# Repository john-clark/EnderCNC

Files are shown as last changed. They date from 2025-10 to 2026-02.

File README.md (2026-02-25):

<div align="center">








## Ender3CNC

Ender3CNC view 1

### About This Project
Got too many Enders laying around? Don't need a [5th Trident?](https://github.com/yell3D/Ender3dent) Well! Try the Ender3CNC, born from a lack of sleep, a wish to learn more CAD and too many spare parts floating around.

</div>

### Reused from the Ender 3
* Frame
* steppers
* wires (might need to extend some)
* leadscrew
* leadscrew nut
* coupler
* mcu
* psu
* most of the nuts and bolts
* v-wheels
* alu spacers
* belts (see BOM)
* limit switches (see BOM)
* screen if you want

### Features
* BOM cost approximately $60 (not counting the Ender 3 PRO or dremel/spindle)
* Chances are you have some of the BOM laying around already.

### Project Links

#### Documentation
* [Manual](https://john-clark.github.io/EnderCNC)
* [Changelog](https://github.com/Futtawuh/EnderCNC/blob/main/Changelog.md)

#### Files
* [STL files](https://www.printables.com/model/1318299-e3cnc-ender-3-pro-based-cnc/files)
* [CAD files](https://www.printables.com/model/1318299-e3cnc-ender-3-pro-based-cnc/files)

#### Software
* Klipper CNC
* Kiri:moto
* [Fusion Post Processor](https://github.com/Zergie/mpcnc_post_processor/blob/main/MPCNC.cps) (Credit: Zergie)
* [How to use/install Post Processor](https://github.com/Futtawuh/EnderCNCs/blob/main/Ender3CNC/fusion360%20post%20processor.md)

---

**Contact:** original author - Ravenkeeper

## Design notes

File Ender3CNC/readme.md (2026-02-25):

# Ender 3 based CNC! [Printables link!](https://www.printables.com/model/1318299-e3cnc-ender-3-pro-based-cnc)





## Fully built

https://github.com/user-attachments/assets/6816d12f-9653-461b-ad77-0ac71268e209

Print settings I used: PLA+, 5 wall, 5 top, 5 bottom, 40% gyroid.

## My setup

Im just running the original MCU with Klipper for the control and Fusion360 for CAM (free version) with a klipperized post processor. So far no real issues. You might want to swap to a board with TMC control (skr pico/micro4) if you realy want to push it.  Im using an old laptop with Ubuntu with klipper on as a substitute for a Raspberry pi.

You can of course go the GRBL route if you want. I just wanted to use klipper since people coming from 3D printers are somewhat familiar with that.

## Check out the ["Build guide"](https://john-clark.github.io/EnderCNC)

- Reusing as much as possible from the Ender 3 PRO down to the screws.
- Cheaper BOM than the original EnderCNC. BOM is mostly just some screws, 2x linear rails for Z and m3/m5 tnuts.
- Easy to scale up or down to any size if not using Ender 3 Pro frame.

### reusing

- Frame
- steppers
- wires (might need to extend some)
- leadscrew
- leadscrew nut
- coupler
- mcu
- psu
- most of the nuts and bolts
- vwheels
- alu spacers
- screen if you want

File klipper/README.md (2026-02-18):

# E3CNC Motherboard Documentation

Creality _USED_ to do a good job of documenting their products and publishing information to GitHub ([https://github.com/CrealityOfficial](https://github.com/CrealityOfficial)**)** and is one of the reasons why they used to be popular. Now they have closed up and so we typically go with 3rd party solutions like BigTreeTech.

_This is just a summary of what we could find on GitHub of needed configuration information for motherboards that were shipped with the Ender 3 for the E3CNC project._

We will include the CR10 as that is very similar to the old Ender3 models. We will not cover newer printers like the Ender-3 V3 series, K1, etc. and their use of custom boards (GD32-based for V3 SE/KE or the STM32F401 on the s1) because these are not suitable for our purposes. Especially with their cost-saving extrusions no longer being repurposable (another change we don’t like that Creality has made.)  
  
This is focused on the E3CNC project and the mainboards that we can ‘upcycle’ printers that would otherwise be sent to the landfill due to manufacturers no longer supporting them.

### Diffference between klipper on a 3D printer and CNC

The E3CNC uses 2 motors and 2 endstops for the Y axis to make sure the gantry is square.

The X axis runs horizontally along the gantry and Z axis runs vertically.

Since we do not use the Extruder, we rearrange the driver assignments for the dual Y axis.

> “The reason we are swapping the X stepper to the E driver is because on the 4.2.2/4.2.7 boards are bit higher "run_current"/amp than the rest of the drivers by default, and since the X motor is alone on the CNC we want it to get more power. Of course, you can adjust Vref though and put them wherever if you want. Just in case you were wondering why steppers and drivers don’t match up” -Ravenkeeper

This goes for pin assignments as well, in Klipper we can assign the bed thermistor or nozzle thermistor to an binary on/off pin just like the endstops.

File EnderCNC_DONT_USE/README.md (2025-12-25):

Cheaper version? - > ["E3CNC"](https://github.com/Futtawuh/EnderCNCs/tree/main/Ender3CNC)

# CAD file for the original EnderCNC

- Loosely based on the Ender 3 pro + Ender 4 with some extras. 
- Made to use up my old spare parts.

https://github.com/user-attachments/assets/380edf0b-43fd-45f2-9f59-4e6d6528cb2b





Here are some videos from the original EnderCNC pre facelift using a 150W 20$ dremel.  

https://github.com/user-attachments/assets/92859aa1-7ed4-4385-81ab-ec51dbf1d837

https://github.com/user-attachments/assets/d6dc1093-e1e1-4dbe-b1f9-021c9d8749b4

# (Residue on the bit is just sticky-tape from doing the holes)

https://github.com/user-attachments/assets/a4f48e41-3836-4eb9-8406-88c55c8b1824

part

120mm bed carriage milled on EnderCNC for a 120mm cubed Voron SW. 


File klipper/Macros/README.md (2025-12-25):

# E3CNC KLIPPER Macros for Workspace XYZ0 Positioning

## What These Macros Do and Why

These macros are designed to **manually set the workspace XYZ0** for basic milling tasks.

When you press a `ZERO` macro, the machine’s current position is saved into a **variables file**. This acts as a backup in case of:

- MCU failure
- Emergency Stop (E-stop) had to be pressed
- Firmware reset or crash

This removes the need to manually record XYZ coordinates before zeroing — everything is saved automatically!

---

## Failed Mid-Job? Firmware Restarted?

>  **Note:** This recovery method only works if you’re using the same workpiece and want to **resume** the job.

### Scenario:
Your job is running, and the MCU crashes, causing a firmware restart.  
Follow these steps to recover:

1. Press the `LOAD_OFFSETS` macro.
    - This will re-home the CNC and move it to the **last saved machine position**.
2. Press the `ZERO_ALL` macro.
    - This re-applies your previous workspace XYZ0.
3. Restart the original job.
    - If you're lucky, this might **save the workpiece** from becoming scrap!

---

## Manual Workpiece ZERO Position Setup

>  **Make sure the Dremel/Spindle is NOT spinning during setup!**

---

### Step-by-Step Guide Manual ZERO:

1. Attach the workpiece securely.
2. Home the CNC machine.
3. Move the CNC via Mainsail to position the bit roughly at the center of the workpiece.
4. Lower the Z-axis until the bit is about **1mm above** the workpiece.
5. Place a **thin sheet of paper** under the bit and slowly lower the Z-axis:
    - Stop when the bit **grabs the paper slightly** (you feel friction).
    - Press the `ZERO_Z` macro — this sets Z0.
6. Raise Z by **2–3mm** to avoid crashing into the workpiece if it’s not perfectly flat.
7. Move the CNC using XY controls to the corner you've defined as the origin in Fusion/CAM.
8. Press `ZERO_X` and `ZERO_Y` macros.
    - ✅ X and Y are now set to workpiece XY0.
    - ❌ Do **not** press `ZERO_Z` again.
9. Start your job from Mainsail.

> **Use PPE, dont crash and stay safe.**

---

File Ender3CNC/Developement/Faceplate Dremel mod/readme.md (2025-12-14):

## Updated dremel clamp to fit the old faceplate for dremels. 
## If you want to use this one you need to print this version of the Beefy dremel clamp, the faceplate DOES NOT fit the original one due to travel loss. 



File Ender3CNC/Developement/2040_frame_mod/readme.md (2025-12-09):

Quick little mod to use only 2040 extrusions on the frame. Usues the original BOM hardware. 





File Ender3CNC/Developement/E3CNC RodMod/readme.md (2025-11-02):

## This RodMod version is just a fun little thing i made up to use some old 12mm rods i had laying around. Works really well though. 
### The "non-Ravenspecial" is Ender 3 PRO based, there are 2x rod on X axis and 3x rod on X axis versions in the CAD.  
### The "Ravenspecial" is my own machine, i used a CR 10 V2 and some other parts i had laying around. 
### You are free to make this version but any support for this version will be on a separate channel on our Discord. I dont know the BOM cost, these are just a side project.

https://github.com/user-attachments/assets/0c3eae66-bfdc-42f0-89b6-0e776cf76d76



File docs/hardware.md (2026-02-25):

# Hardware Overview

This guide covers the core hardware needed to convert your Ender 3 (or Ender 3 Pro) into a desktop CNC machine. Parts are broken into reused components, items to purchase, and optional upgrades. Wherever possible, the BOM is aligned with common Voron 3D printer parts to make sourcing easier for hobbyists.

## Reused Ender 3 Parts

* **Frame & Structural Components** – keep most of the original aluminum extrusions and screws.
* **Electronics** - Original V1 and V4 MCU's have been tested.
* **Motors & Wiring** – stepper motors, wiring harnesses, and couplers.
* **Limit switches** – reuse up to 3, but you’ll need at least 1 additional switch.
* **Belts & Bearings** – 2 belts can be reused; plan to buy extra. Use existing bearings.
* **Fasteners** – most M3, M4, and M5 nuts and bolts can be salvaged.

!!! Note
    Modifications such as cutting the top 2020 extrusion for the z-axis require careful measurement.

## Differences betwen Ender 3 printers

Before diving in there a few key differences between versions of Ender 3 3D printers and are worth noting. This may affect your decision if you are looking at models for this project.

* Ender 3 and Ender 3 pro are essentially the same for the CNC conversion, the most significant difference is the extrusion used for the gantry (the Y extrusion that the Bed rides on).
* The rest of Ender 3 models are not covered here as they have not been tested but are here for awareness, they may or may not be suitable.

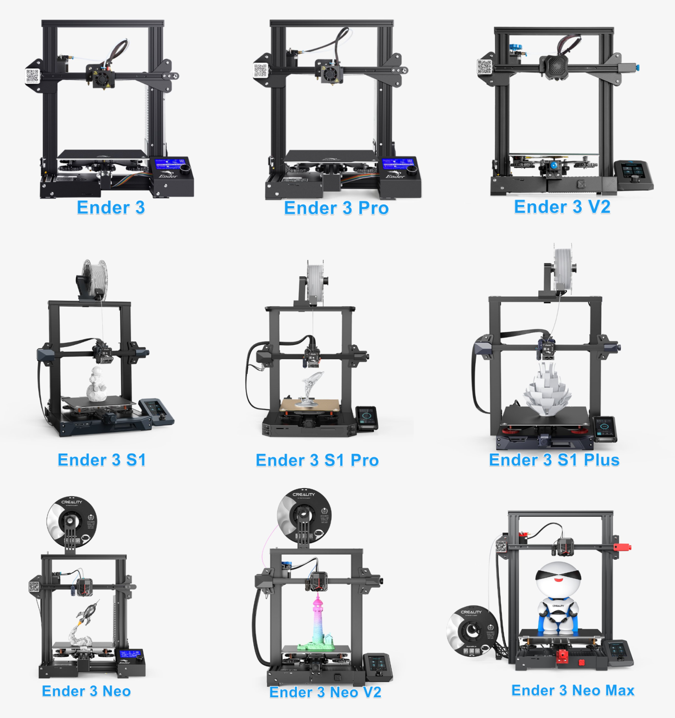
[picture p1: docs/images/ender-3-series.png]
Ender 3 vs pro


### Differences

| Part | Ender 3  | Ender 3 Pro | CNC Implication |
| --- | --- | --- | --- |
| Y-axis plate Extrusion | 2040 | 4040 | Gantry needs a 300mm extrusion purchased if original Ender 3 |
| V-wheels / rollers | Plastic  | Slightly higher quality | CNC conversion uses same wheels but alignment becomes critical. |
| Screws & T-nuts | Standard | Some upgraded | Reuse as much as possible; minor differences. |
| Electronics | V1.1.x | V4.2.x | The Pro version is a better MCU |

!!! note
    There is a mod to utilize the 2040 v-slot 300m gantry extrusion on the non pro but we do not recommend it. We recommend buying 2x 2040 v-slot 300m extrusions for $12 and fabricating the 4040 that the pro comes with and is explained in the gantry section.

## Parts from Ender 3 

| Qty | Part Description | Notes |
|-----|---|---|
| **Extrusions** |
| 1x  | 2020 v-slot Profile | To be cut in half |
| 2x  | 4040 v-slot Profile | |
| 2x  | 2040 v-slot Profile | |
| 1x  | 4040 v-slot Profile | Ender 3 Pro Only |
| **M5 Screws** |
| 10x | M5x30 button head | |
| 16x | M5x45 bolts | From the frame (remove shims) |
| 4x  | M5x8 | |
| 1x  | M5x65 | Middle lower X axis wheel |
| All | M5 nuts | |
| **M4 Screws** |
| 2x  | M4x20 | |
| 2x  | M4x16 | |
| 2x  | M4x10 | Includes 2x M4 t-nuts |
| **M3 Screws** |
| 6x  | M3x10 | |
| 11x | M3x10 | Additional needed |
| 4x  | M3x40 | |
| 12x | M3x6 | |
| **Bearings** |
| 2x  | 688 bearings | If available |

!!! Note
    You can re-use 2 belt lengths from the Ender 3, but you still need one more ~350mm length. 

!!! Tip
    You can re-use 3 limit switches from the Ender 3, if you want to cut them off the PCB's but you'll still be missing 1, so you need to order AT LEAST 1 more, it is probably easier just to buy a new set if you go with this option. The recommendation is to go with the endstop mod.

## Parts to Purchase (BOM) Bill of Materials

| Qty | Part Description | Specifications | Notes |
|-----|---|---|---|
| **Extrusion** |
| 2x  | 2040 v-slot | 300mm | Only for Original Ender |
| **Motion Components** |
| 3x  | GT2 belts | 350mm length, 6mm width  | Buy 3-5 meter roll |
| 3x  | GT2 pulleys | 20T, 6mm width, 5mm bore | |
| 2x  | MGN12H linear rails | 150mm length | 1 carriage per rail |
| 2x  | 608ZZ bearings | 8x22x7mm | Or use 688 from Ender 3 |
| **Electronics** |
| 4x  | D2F-L Microswitch | Limit switch | Get 10 pack / use original |
| **Fasteners** |
| 20x | M3 T-nuts | For 2020 extrusion | Sliding or standard t-nuts |
| 40x | M5 T-nuts | For 2020 extrusion | Sliding or standard t-nuts |
| 10x | M5 locknuts | Hex nuts | |
| 70x | M5x16 button head | | |
| 22x | M3x10 screws | Not countersunk | |
| 12x | M3x8 SHCS | Socket head cap screws | |
| **Hardware** |
| 30x | Heat set inserts | M3x4x5mm | Voron spec |
| 4x  | M5 shims | OD 10mm, ID 5mm, 1mm | Washers |

## Optional Upgrades

| Qty | Part Description | Specifications | Purpose |
|-----|---|---|---|
| 8x  | Aluminum spacers | 5mm ID x 8mm OD x 8mm length | Replaces printed Y axis wheel spacers |

---

## Self sourcing 

!!! warning
    If you can't find a reasonable priced Ender 3 you can self source the parts from the jungle store.

This is to give you an idea of the cost if you were to build your own classic Ender 3 printer. It does not include all the parts that came with the original Ender, it is just a ballpark figure for people interested. When buying it is cheaper to buy in quantity to save money so our example here is for two printers.

**Cost for profiles:**

- 2020 profiles - 330 + 345 = 675 mm [Amazon $18](https://www.amazon.com/Seekliny-Aluminum-Extrusion-V-Slotted-Accessories/dp/B0DY7D8B23) 2 extra
- 2040 profiles - 330 + 400 + 400 = 1,130 mm [Amazon $18](https://www.amazon.com/400mm-Aluminum-Extrusion-European-Standard/dp/B0DST7TW3Z) 0 extra so buy 2 $36
- 4040 profiles - 250 + 290 + 290 = 830 mm [Amazon $55 4x600mm](https://www.amazon.com/Aluminum-Extrusion-European-Standard-Anodized/dp/B09MYGZDW4)  cut to appropriate length enough for 2

**Two frames total = $109/2 or $55 each**

**Other essential parts**

- Power supply [Amazon $22](https://www.amazon.com/SHNITPWR-Switching-Converter-Transformer-Security/dp/B07TWW8Q73) x2
- 42-34 Motor [Amazon $27](https://www.amazon.com/YEJMKJ-Stepper-41-07oz%C2%B7-Bipolar-Printer/dp/B0FHHV9JZG) x2
- 42-40 Motor [Amazon $22](https://www.amazon.com/Printer-Stepper-42-40-Extruder-Creality/dp/B0CSW9KG8H) 1 each

**Total for 2 (frame/motor/power) = $229 (add 2x$50 electronics) or about $170 each**

---

## Ready to Proceed?

Once you have the required parts, continue to the next section to review required printed parts.

<p align="center">
  <a href="/EnderCNC/printed_parts" class="md-button md-button--primary">
    Continue to Printed Parts →
  </a>
</p>

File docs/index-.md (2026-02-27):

# Ender 3 CNC Build Manual

!!! warning "Early Release"
    This is Version 1 of the manual. Expect frequent iterative improvements.
    
**Converting a Proven Motion Platform into a Precision CNC System**

The Ender 3 is a well-understood, mechanically consistent motion platform. Ender3CNC transforms it into a capable desktop CNC machine — not as a novelty conversion, but as a deliberate, mechanically considered upgrade. We want to save machines from the landfill and give them a new purpose.

This manual provides a structured, engineering-focused pathway to convert a standard Ender 3 (or Ender 3 Pro) into a rigid, repeatable CNC platform using:

* Documented design decisions
* Tested configurations

The result is a machine capable of cutting hardwood, plastics, and aluminum while maintaining affordability and accessibility.

---

## Design Philosophy

This project is not about bolting a spindle onto a printer. It is built around these engineering priorities:

**Maximum Reuse** - Retain as much of the original machine as possible — frame, motion components, electronics — to reduce cost and complexity. Save the planet!

**Controlled Scalability** - Allow adaptation to custom frames or expanded builds without redesigning the entire system.

Every modification exists for a reason: improved stiffness, reduced deflection, better load handling, or cleaner integration.

---

## Performance Snapshot

While this is still a developing platform, current test results demonstrate:

* Stable hardwood cutting
* Aluminum machining with conservative feeds
* Repeatable part production

The conversion reinforces primary load paths and implements independent dual Y-axis control, reducing racking, improving torsional resistance, and increasing positional stability under machining forces. Final performance depends on tool selection, feeds and speeds, spindle choice, and tuning quality.

This is not an industrial VMC. It is a capable, budget-conscious desktop CNC system when built and configured properly.

---

## Who This Project Is For

* Makers comfortable assembling mechanical systems
* 3D printer users familiar with firmware configuration
* Hobbyists looking for an accessible CNC entry point
* Builders who value reuse and system optimization
* Tinkerers who enjoy iterative improvement

## Who This Project Is Not For

* Users expecting plug-and-play CNC performance
* Production shops requiring industrial tolerances
* Builders unwilling to tune firmware or align mechanical systems
* Anyone uncomfortable with troubleshooting

This build rewards patience and mechanical understanding.

---

!!! note "Work in Progress"
    This documentation is under active development.
    Revisions, refinements, and corrections are ongoing.
    If you encounter an issue or want to contribute feedback:
    [https://github.com/john-clark/EnderCNC/issues](https://github.com/john-clark/EnderCNC/issues)
    
---

## What You’ll Build

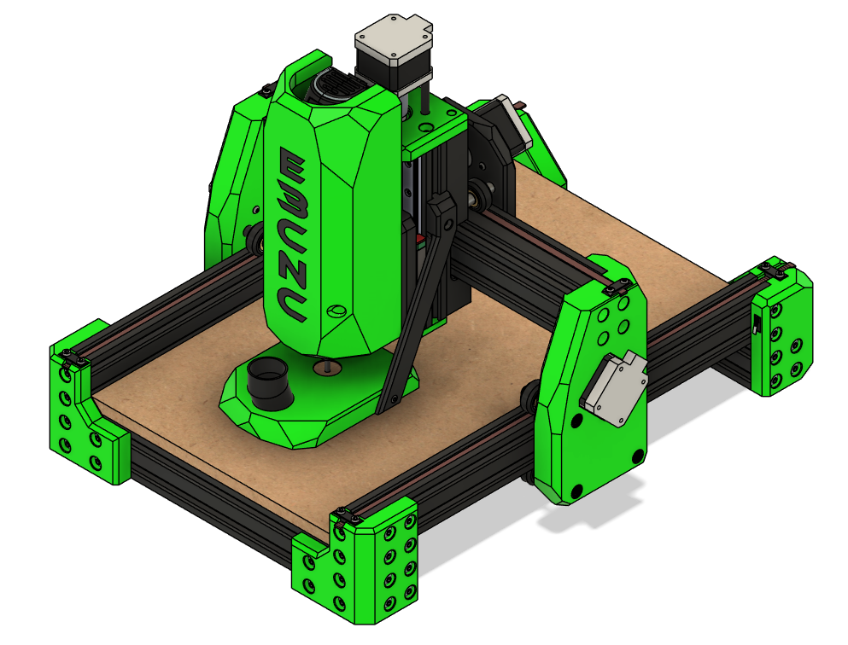
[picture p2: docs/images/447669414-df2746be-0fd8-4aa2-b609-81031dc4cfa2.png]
Ender3CNC Build 1

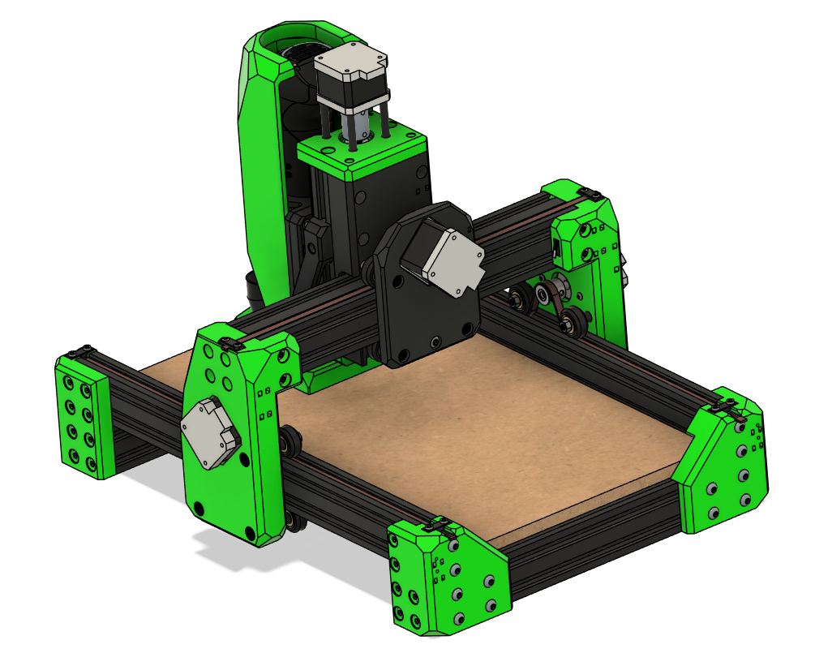
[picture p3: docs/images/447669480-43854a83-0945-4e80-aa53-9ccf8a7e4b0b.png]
Ender3CNC Build 2


!!! success "Build Gallery"
    See user builds in the [Gallery](Builds/gallery.md)

---

## Control Architecture

Tested Reference configurations:

* Original Ender 3 MCU, and other aftermarket 3D printer MCU's with Klipper firmware
* Fusion 360 (free version), FreeCAD, or Kiri:moto for CAM
* Ubuntu laptop running Klipper (as Raspberry Pi substitute) as a Klipper Post proceesor

This configuration has proven stable during testing.

A GRBL workflow is also viable. Klipper was selected to reduce the learning curve for users transitioning from 3D printing and reuse existing electronics.

---

## Reused Components

The system intentionally retains:

* Frame (cutting required)
* Stepper motors
* Wiring (some extensions may be required)
* Leadscrew and nut (cutting required)
* Coupler
* MCU
* Power supply
* Most fasteners
* V-wheels
* Aluminum spacers
* LCD (optional)

The goal is not reinvention — it is optimization.

Complete details in the BOM.

---

## Ready to Proceed?

This manual will guide you through tools, parts, mechanical conversion, and configuration.

<p align="center">
  <a href="tools" class="md-button md-button--primary">
    Begin with Required Tools →
  </a>
</p>

---

## Need to see more?

<p align="center">
  <a href="Builds/gallery" class="md-button md-button--secondary">
    View the Build Gallery →
  </a>
</p>

!!! tip "Recommended Approach"
    Follow the chapters sequentially. Mechanical alignment, structural rigidity, and configuration steps build on one another.

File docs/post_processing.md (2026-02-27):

# What is a Post Processor?

The first step in the process is to create a design using CAD (computer-aided design software), which is separate to the CNC programming software. You can think of this as a blueprint for your design.

You then need to use CAM software, which takes your CAD drawing file and creates a g-code. G-code is the most widely used CNC programming format and essentially provides information to the CNC machine about what work needs to be done.

The CNC control software is directly connected to the CNC controller with a transfer protocol, usually a parallel DB25 port or USB. The controller then directs the central breakout board which in turn sends instructions to the drivers, based on the information provided by the software. The drivers provide instructions to the motors, which control each axis to create models.

A **post processor** is a software component that translates the toolpath information generated by your CAM software (like Fusion 360) into **G-code instructions** your CNC machine can understand. Think of it as the "interpreter" between your design and your machine’s motors.

Without the correct post processor, your CNC may **move incorrectly, ignore settings, or even crash**.

---

## How it Fits Into the Workflow

1. **Design**
   Create your part in CAD software (Fusion 360, FreeCAD, etc.). Define dimensions, shapes, and features.

   You may want to look at programs like [Deepnest](https://deepnest.io/) at this stage.

2. **CAM (Computer-Aided Manufacturing)**
   Generate **toolpaths** for your part. Toolpaths include the cutting moves, speeds, feeds, and spindle operations.

3. **Post Processor**
   Convert the generic toolpaths into **machine-specific G-code**. This step ensures that your instructions match the firmware, kinematics, and hardware of your CNC.

   * Example: The **Klipperized post processor** adapts toolpaths to standard Klipper commands.
   * It handles nuances like:

     * G0/G1 rapid vs. linear moves
     * Motor steps and acceleration
     * Machine coordinates and offsets
     * Tool change commands (if applicable)

4. **CNC Controller**
   Load the generated G-code into your CNC controller (Mainsail, Fluidd, or other Klipper interfaces).
   The controller executes the commands, moving your machine precisely along the toolpaths.

5. **Cutting / Milling / Engraving**
   Watch your design come to life as the CNC follows the instructions accurately.

### Visual Workflow

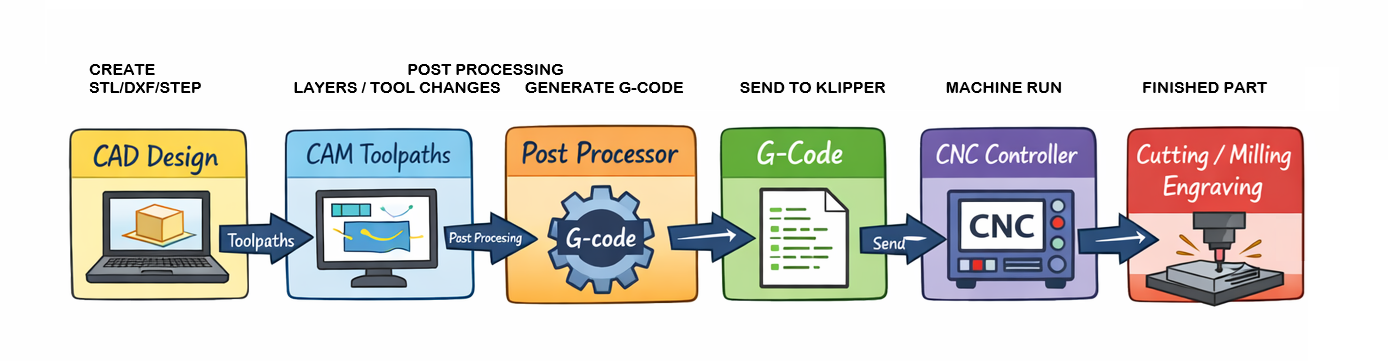
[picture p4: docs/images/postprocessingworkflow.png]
workflow


---

## Why You Need the Right Post Processor

Every machine is slightly different: frame size, stepper drivers, firmware, and even how axes are defined can vary. The **post processor ensures your CAM output matches your hardware exactly**, avoiding crashes, misalignments, or wasted material.

### Key Benefits

* Prevents collisions and crashes
* Ensures accurate scaling and positioning
* Supports machine-specific features (like dual Y-axis in Ender3 CNC)
* Optimizes travel moves and feed rates for performance and longevity

!!! Tip
    Always simulate the G-code in your CNC software (like OctoPrint, Mainsail, or Fluidd) before running a real cut. Even with the right post processor, checking ensures safety and accuracy.

---

## Choose a Post Processor

<p align="center">
  <a href="/EnderCNC/fusion360" class="md-button md-button--primary">
    Fusion 360 →
  </a>

  <a href="/EnderCNC/freecad" class="md-button md-button--primary">
    FreeCAD →
  </a>

  <a href="/EnderCNC/kirimoto" class="md-button md-button--primary">
    Kiri:moto →
  </a>
</p>

---

## CNC Simulation

* [CAMotics](https://camotics.org/)
* [NC Viewer](https://ncviewer.com/)
* [Kiri:moto](https://grid.space/kiri/)

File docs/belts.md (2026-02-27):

# Belts and Spindle 

This chapter covers routing the GT2 belts.

---

## 1. Parts Required

| Qty  | Item | Source  | Notes |
|---|---|---|---|
| 3pc  | ~500mm GT2 6mm Belt | Buy | Measure carefully before cutting |
| 12pc | M3x10 | Buy | Some may be spare from Ender3 |
| 6pc  | Printed Belt Clamp | Printed | Holds belt ends securely |

---

## 2. Belt Installation

1. Route GT2 belts along X and Y axes.  
2. Use printed belt clamps to secure belt ends.  
3. Ensure belts are **tight but not overly stretched**.  
4. Test X/Y motion manually to confirm smooth travel.

---

## Ready to Proceed?

You are now ready to move on to spindle attachment and **Tool Selection**.

<p align="center">
  <a href="/EnderCNC/spindle" class="md-button md-button--primary">
    Continue to Tool Selection →
  </a>
</p>

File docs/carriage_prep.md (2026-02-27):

# Carriage Assembly

This chapter covers assembling the carriage, mounting motors, bearings, and spacers.

---

## Parts Required

| Qty | Item | Source | Notes |
|---|---|---|---|
| 4pc | M3x8 BHSC | Ender3 | |
| 2pc | M3x10 | Buy | |
| 10pc  | M5x16 BHSC | Buy | |
| 2pc | M5x8 BHSC | Ender3 | |
| 4pc | M3x40 | Ender3 | |
| 4pc | M5x45 SHSC | Ender3 | Remove shims |
| 1pc | M5x65 BHSC | Buy | |
| 12pc  | M3x8 SHSC | Buy | |
| 2pc | M3x16 BHSC | Ender3 | |
| 9pc | Aluminum Spacers | Ender3 | |
| 1pc | 28.35mm Printed Spacer  | Printed  | |
| 5pc | V-Wheels | Ender3 | |
| 4pc | 32.60mm Printed Spacer  | Printed  | |
| 8pc | M3x10 BHSC | Ender3 | |

---

## Assembly Exploded

For reference only, this will be explained step by step.

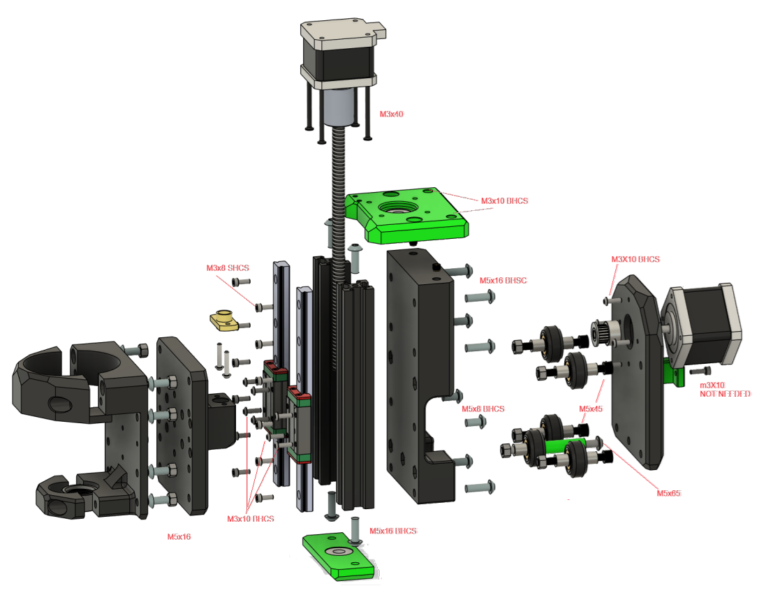
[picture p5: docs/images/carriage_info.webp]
Exploded Assembly


---

## Cut the Top rail into 2 150mm pieces for Z axis

!!! Tip
    When cutting the z rail start with the center cut `1` and then cut the outside through holes off so there is more extrusion to thread on to and it is easier to make sure they are the same length.
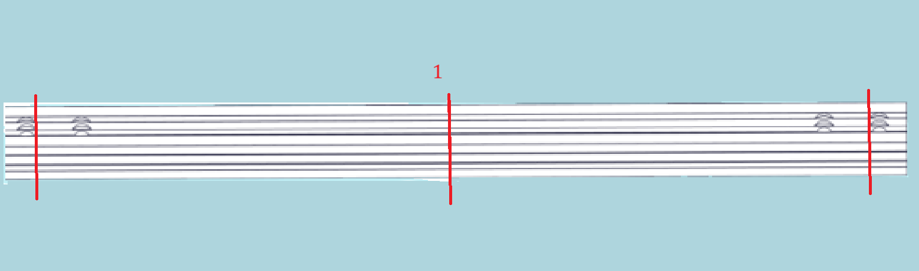
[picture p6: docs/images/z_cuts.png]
cut 2020
    

---

## Install heatsets and pressfits for the carriage.

### Parts Required

| Qty | Item | Source | Notes |
|---|---|---|---|
| 7pc | M3 Heatsets | Buy |  M3x5x4 "Voron spec" |
| 12pc  | Lock Nuts | Buy | |

### Heatsets

!!! warning
    Make sure heatsets are flush and perpendicular.
    
**XZ Carriage Plate**

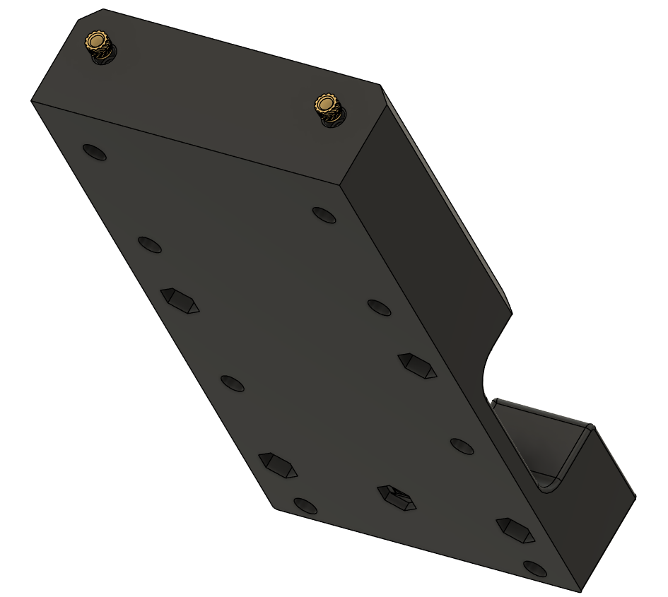
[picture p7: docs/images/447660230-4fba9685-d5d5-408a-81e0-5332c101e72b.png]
XZ_gantry_heatsets


**Dremel Plate**

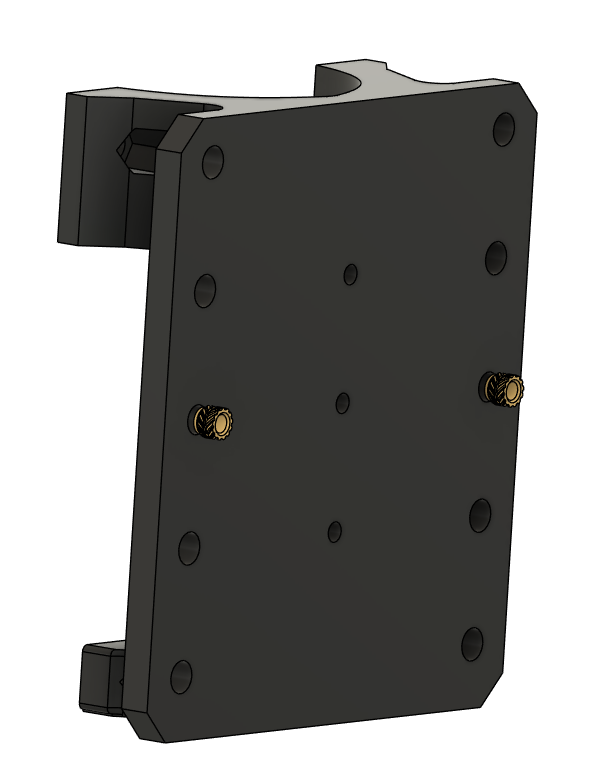
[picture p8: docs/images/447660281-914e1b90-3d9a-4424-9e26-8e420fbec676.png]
dremel_plate_heatset


**Z Carriage**

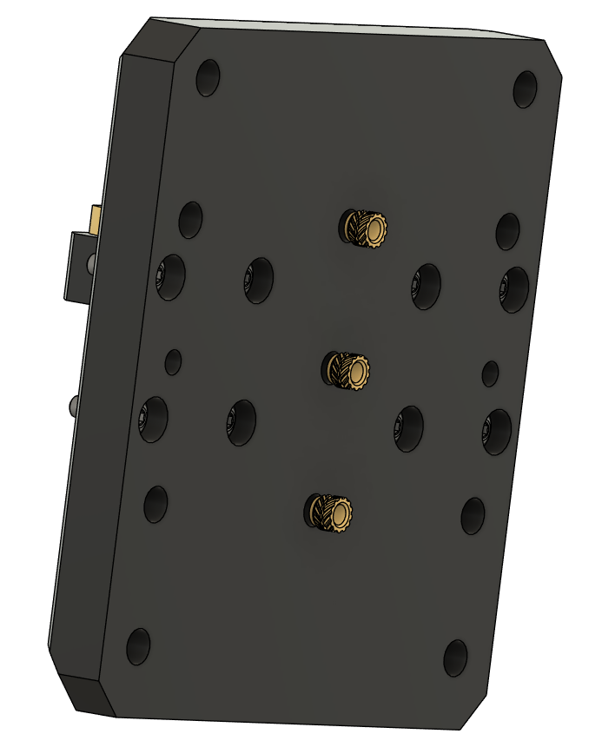
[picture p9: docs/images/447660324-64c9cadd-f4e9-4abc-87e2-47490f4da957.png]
Z_carriage_heatsets


**X-Motor plate**

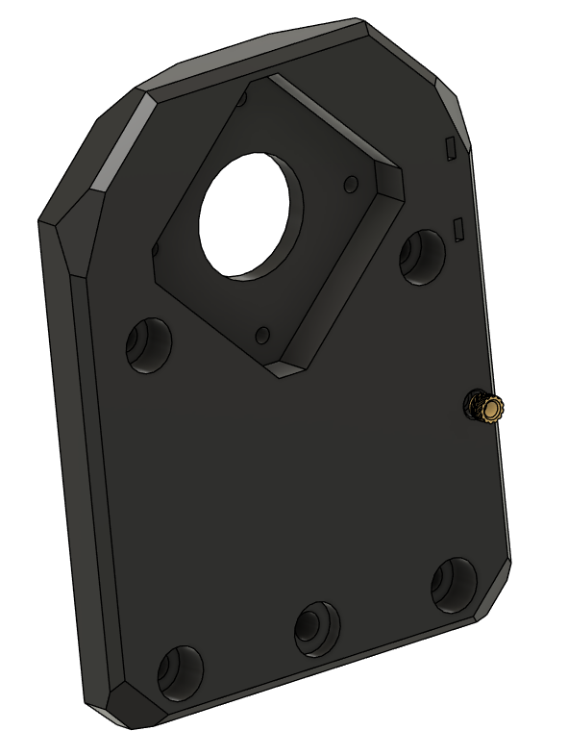
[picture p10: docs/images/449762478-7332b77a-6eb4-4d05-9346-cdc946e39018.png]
x_motor_heatsets

    
---

### Pressfit Locknuts

!!! tip
    You may want to add a dab of superglue to the lock nuts to keep them in place.

**Z Carriage**

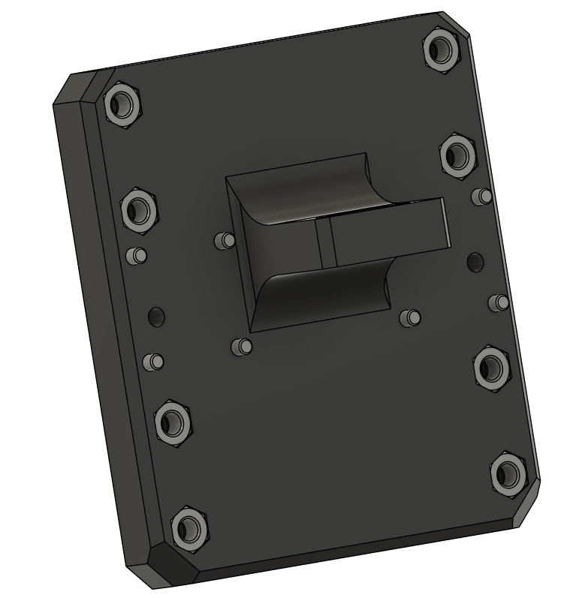
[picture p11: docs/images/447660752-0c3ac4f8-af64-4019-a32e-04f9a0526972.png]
Z_carriage_locknuts


**XZ Carriage Plate**

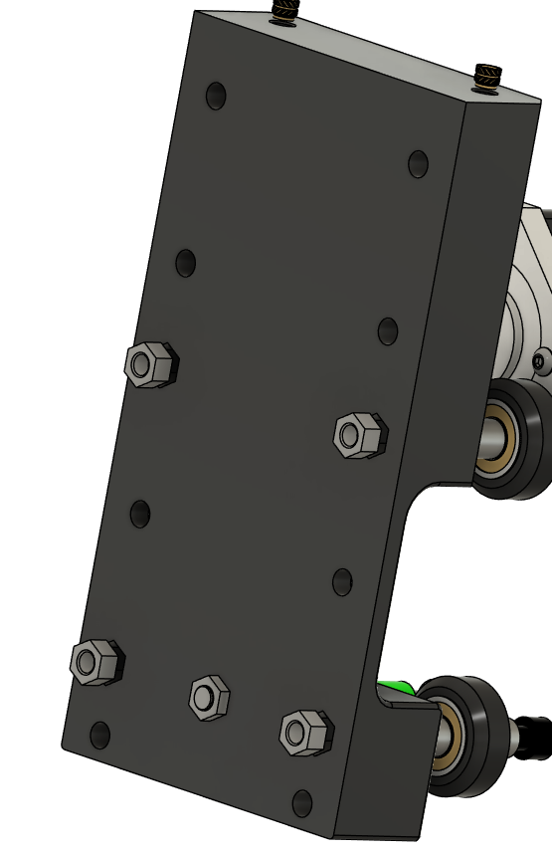
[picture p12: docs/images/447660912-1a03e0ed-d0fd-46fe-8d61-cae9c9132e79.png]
XZ_gantry_locknuts


---

## Ready to Proceed?

After completing these steps, your start assembling the **Carriage Assembly**.

<p align="center">
  <a href="/EnderCNC/carriage_assembly" class="md-button md-button--primary">
    Continue to Carriage Assembly →
  </a>
</p>

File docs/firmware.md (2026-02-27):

# Firmware Setup

This chapter explains firmware options for your Ender 3 CNC conversion.

---

## Supported Options

| Firmware | Notes |
|---|---|
| Klipper  | Recommended if a Raspberry Pi or old laptop is available |
| GRBL | Standard CNC option, must purchase an ESP32/32-bit board |

---

## Klipper Setup

1. Follow standard Klipper installation on your Raspberry Pi or Linux laptop. We recommend [dw-0/kiauh](https://github.com/dw-0/kiauh) to get started.

2. Copy a reference `printer.cfg` for the Ender CNC:
   * Make sure the stepper, endstop, spindle, and belt parameters are correct for your MCU
   * Make sure all motors are spinning correctly and settings are correct for your MCU
  
3. Test all axes manually before enabling motor power.

4. Configure homing and probe offsets for your spindle.

### Example configs

* [Version 1.1.x Ender MCU printer.cfg](https://github.com/john-clark/EnderCNC/blob/main/klipper/v1.1.x_printer.cfg) Original Ender 3
* [Version 4.2.2 Ender MCU printer.cfg](https://github.com/john-clark/EnderCNC/blob/main//klipper/v4.2.2_printer.cfg) Ender 3 Pro
* [Version 4.2.7 Ender MCU printer.cfg](https://github.com/john-clark/EnderCNC/blob/main//klipper/v4.2.7_printer.cfg) Latest Ender 3 pro

### How to document your mainboard

Notice in the picture that the processor and motor has documented pins.

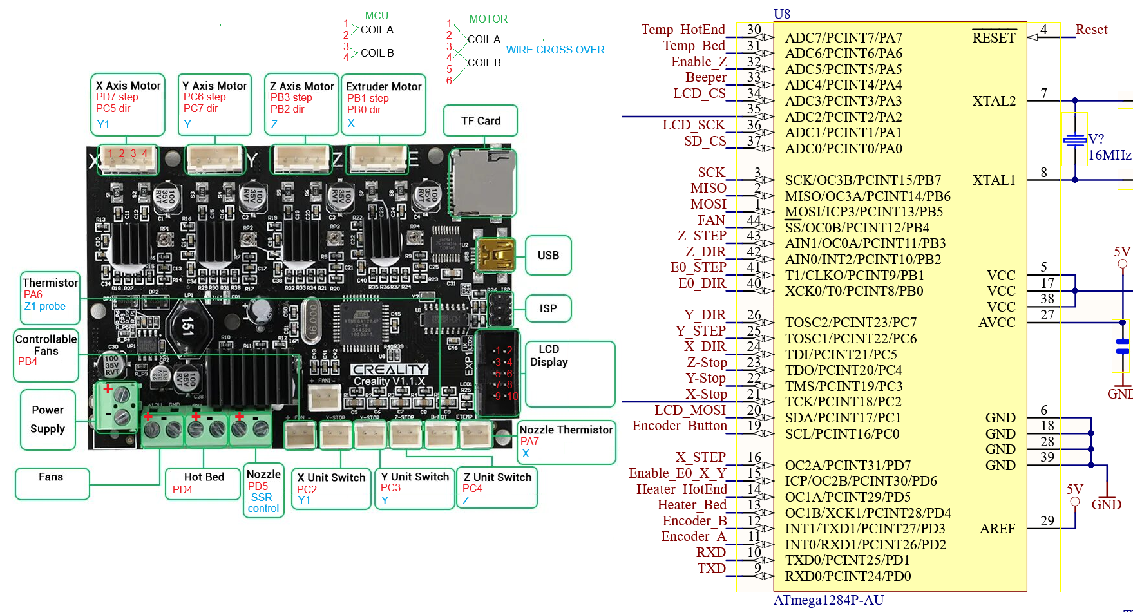
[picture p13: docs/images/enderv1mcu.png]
Creality v1 mcu


---

## GRBL Setup / FluidNC

1. Flash your GRBL-compatible board according to manufacturer instructions.  
2. Use the reference configuration for stepper settings, endstops, and spindle control.  
3. Test movement manually before running any G-Code.

**[FluidNC](https://eghasemy.github.io/FluidNC_GUI/docs/getting-started/understanding-fluidnc/) Setup**

**Typical GRBL CAM software**

* [Candle](https://github.com/Denvi/Candle)
* [OpenBuilds](https://software.openbuilds.com/)
* [PlanetCNC](https://planet-cnc.com/download.html)

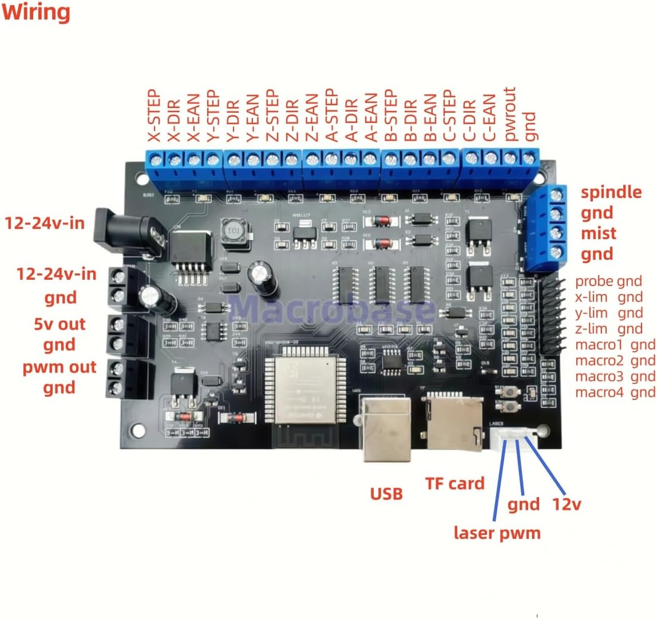
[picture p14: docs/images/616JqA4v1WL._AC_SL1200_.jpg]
Macrobase MCU


---

### IMPORTANT NOTES

>Don't let the magic smoke out!

!!! tip
    Keep a backup of working firmware configuration before making major changes.

!!! warning
    Never run motors at full speed during first test

!!! warning
    Verify wiring because Creality motors have crossover wires.

!!! warning
    Y axis has one motor inverted. Test Y motor without belts first.

---

## Ready to Proceed?

You have now completed Ender3CNC build and you can now do **Trouble Shooting** or move onto **Post Processing**.

<p align="center">
  <a href="/EnderCNC/troubleshooting" class="md-button md-button--warning">
    Troubleshooting →
  </a>

  <a href="/EnderCNC/post_processing" class="md-button md-button--primary">
    Post Processing →
  </a>
</p>

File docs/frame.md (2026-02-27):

# Frame Assembly

This chapter walks through building the Ender 3 CNC frame.

---

## Parts Required

| Qty  | Item | Source  | Notes |
|---|---|---|---|
| 48pc | M5x16 BHSC | Buy | Frame bolts |
| 4pc  | M5x40 | Ender3  | Z-axis attachment |
| 4pc  | M5x8 | Ender3  | Extra spacers |
| 4pc  | M5 1mm Shims | Buy | For precise leveling |
| 52pc | M5 T-nuts | Buy | Frame assembly |
| 2pc  | 4020x400mm | Ender3  | Extrusion |
| 2pc  | 4040x290mm | Ender3  | Extrusion |

---

## Ready Extrusion

### Cut Extrusion (if needed)

1. Measure your frame; Ender 3 frames may vary ± a few mm.  
2. Cut extrusion to size (use a machinest square to make sure they are square.)
4. Tap **4 new M5 threads** on the cut side.  

!!! tip
    If you are unsure, measure six times before cutting. Once cut, you cannot undo it.

---

### Drill Through holes for Blind joints

These allow you to put a hex key through the hole to tighten the bolt below.

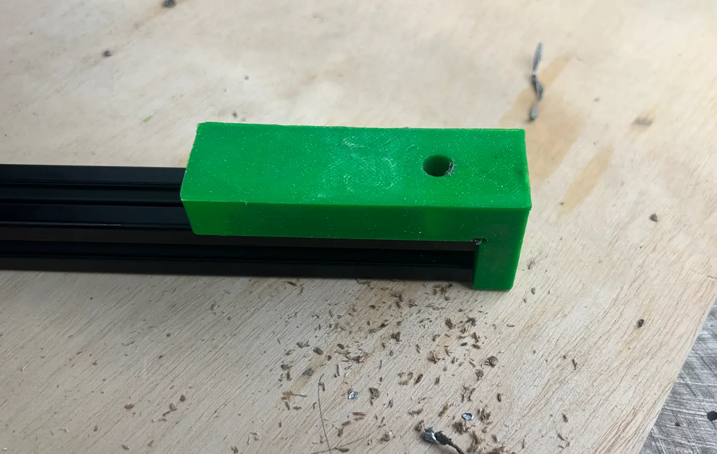
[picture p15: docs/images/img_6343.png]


### should be 20mm on center offset both front and back. 
  
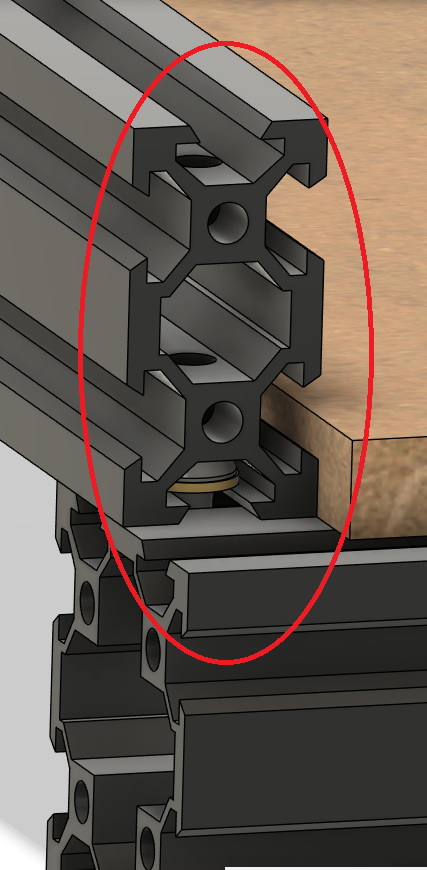
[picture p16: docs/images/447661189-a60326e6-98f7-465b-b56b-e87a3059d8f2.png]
blind joint back


---

#### Tap Ends 

of all the Extrusions

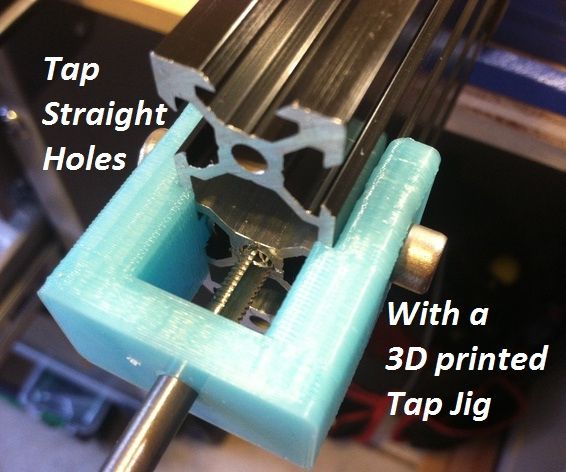
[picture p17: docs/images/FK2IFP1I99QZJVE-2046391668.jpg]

---

## Add Heat Inserts

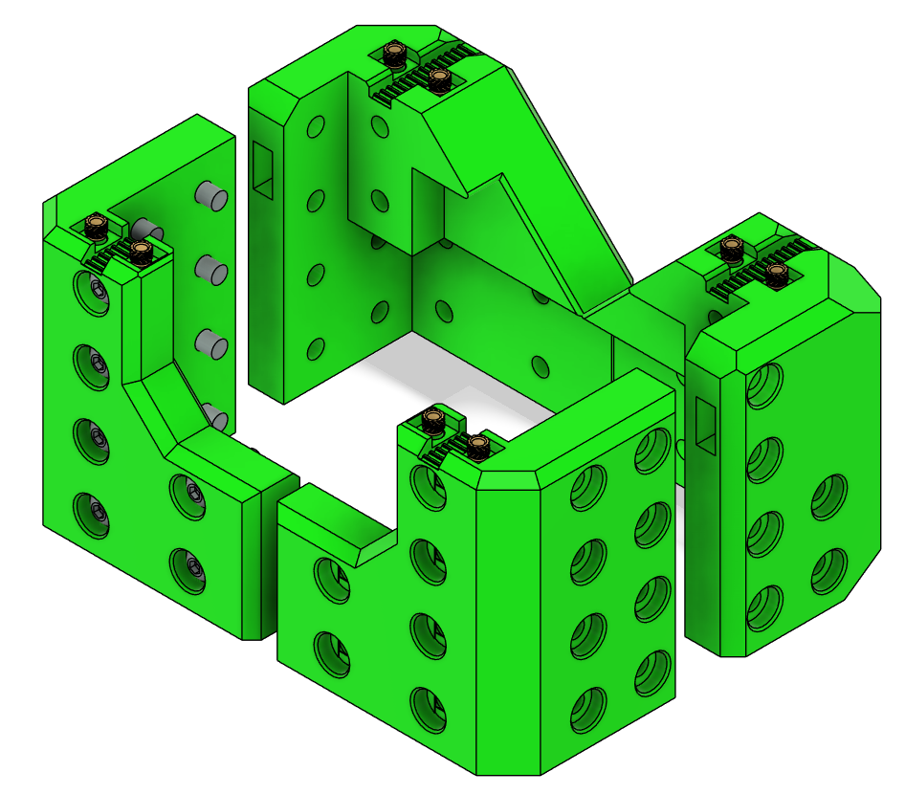
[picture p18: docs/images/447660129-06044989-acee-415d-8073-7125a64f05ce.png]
Frame Assembly


---

## XY Joints

1. Lay out the aluminum extrusions with 4040s on the ends and 4020s perpendicular.  
2. Take note of **blind joints** and the **20mm offset** on the extrusion.  
3. Loosely attach M5 bolts and T-nuts to hold the frame together on one side.  

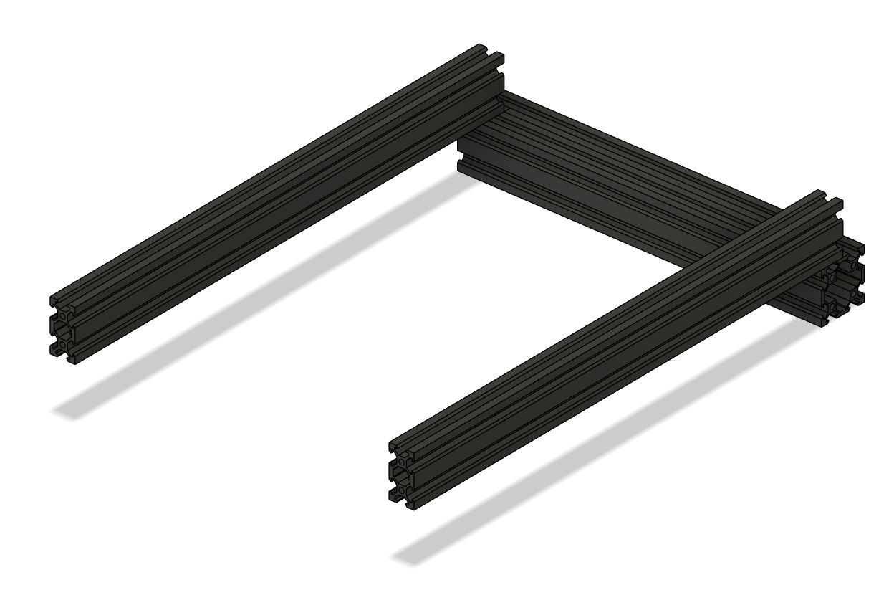
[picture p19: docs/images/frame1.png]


!!! tip
    Leave loose until all corners are in place.

4. Mount XY Joints to Frame¶

    * Slide the XY joints onto the 2020 frame extrusions
    * Place the bottom V-wheels into the V-slot.
    * Loosely add M5 locknuts to the bottom wheels.
    * Tilt the XY joint slightly to insert the top wheels into the V-slot.
    * Wiggle the assembly so the top screws pop into place.

    !!! Warning
        The XY joints are pressfit in some positions; force gently and double-check alignment.

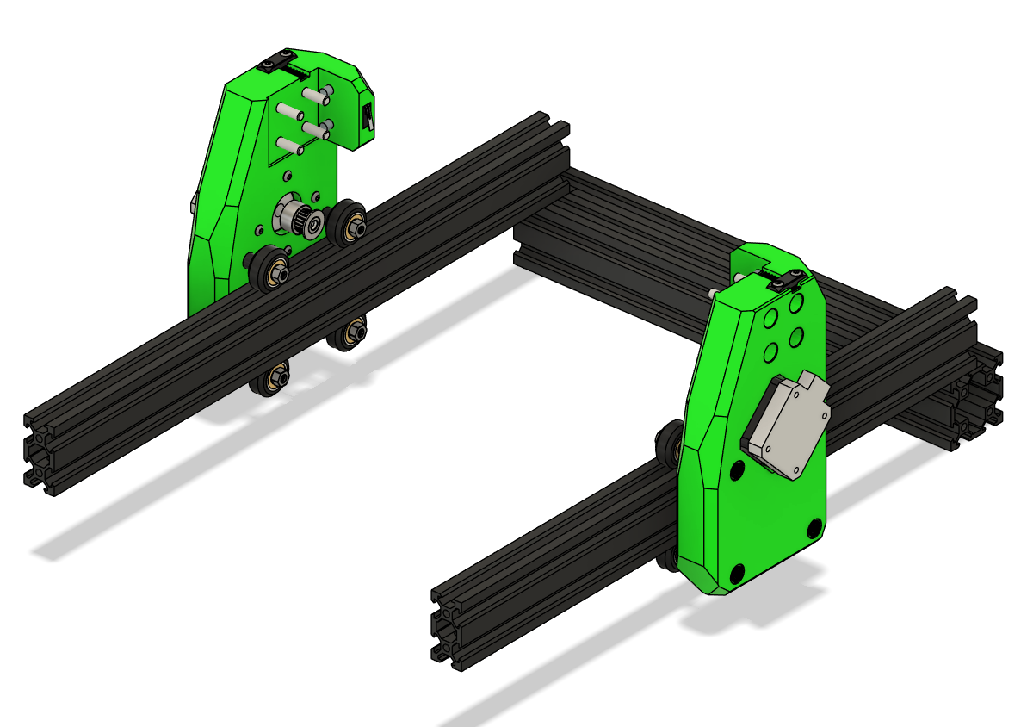
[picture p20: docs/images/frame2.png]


5. Add the front 4040 and loosely attach M5 bolts and T-nuts.

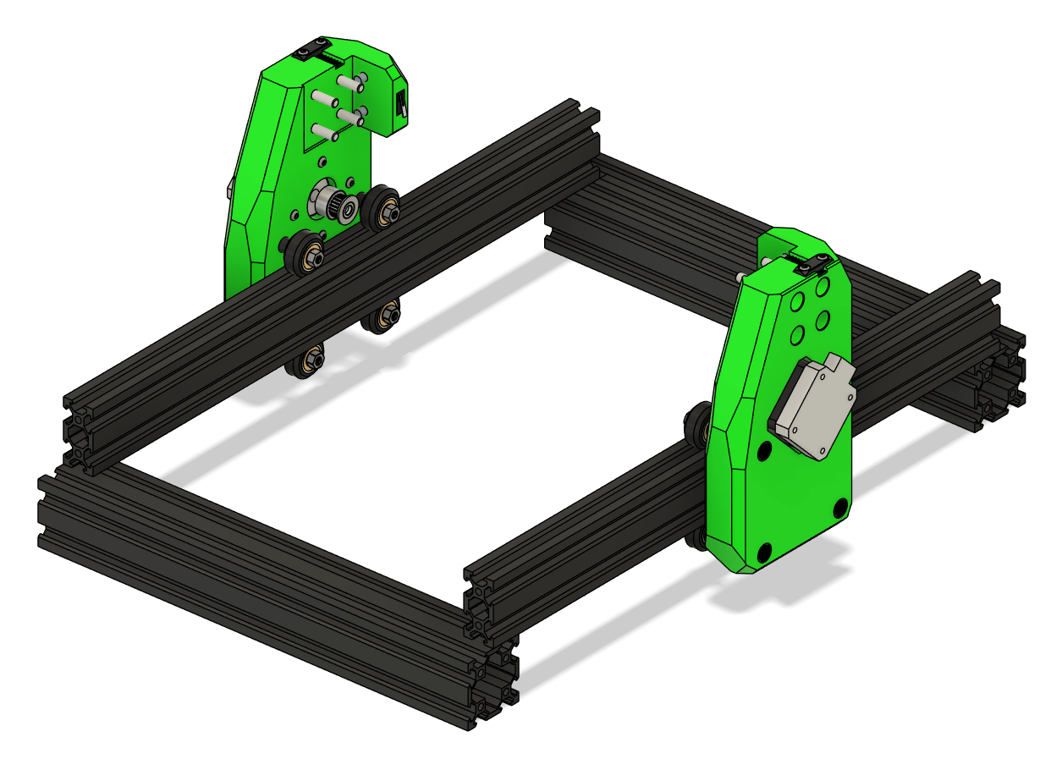
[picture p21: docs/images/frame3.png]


6. Attach corners

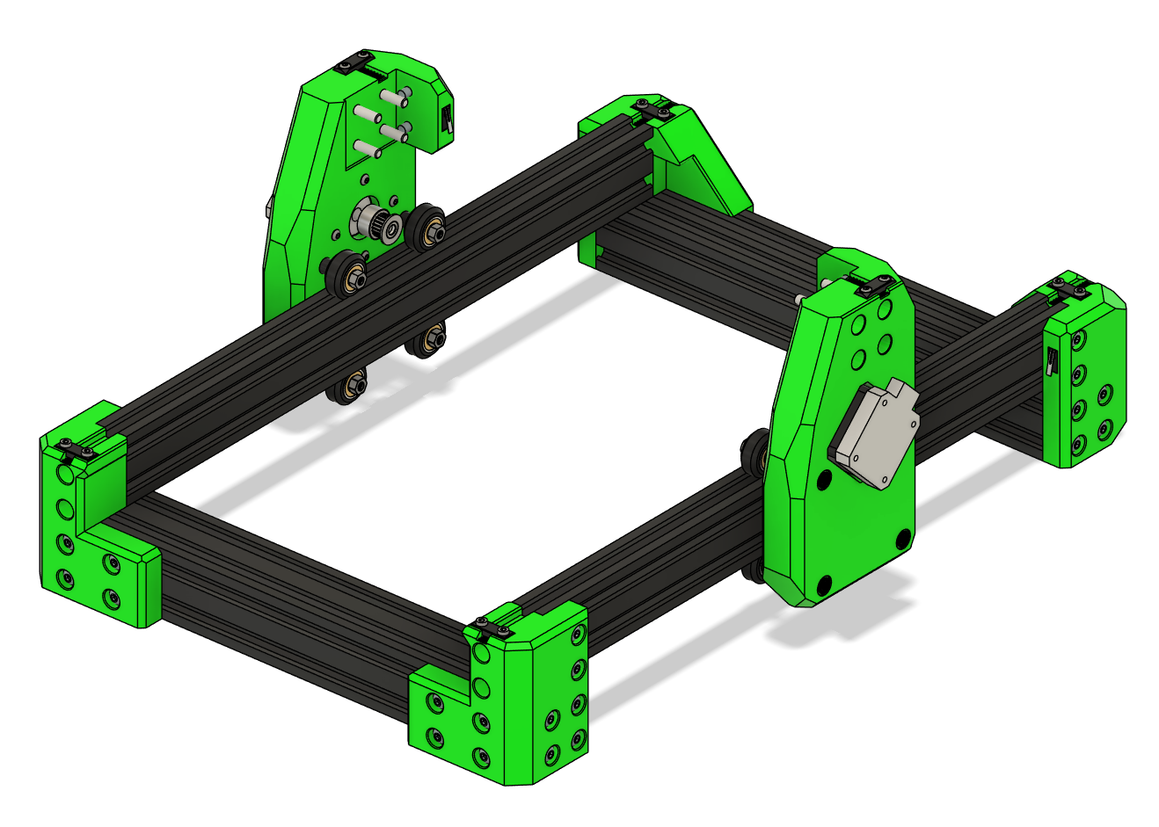
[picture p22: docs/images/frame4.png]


7. Check that the frame is **square**:
   - Measure diagonals; they should be equal.  
   - Adjust joints as necessary.
   - **Fully tighten all the bolts**

!!! tip
    Use a **flat surface** when squaring the frame for best results.

---

### Check Alignment
* Measure the distance between the X extrusion mounting points — Ender 3 frames may vary by ± a few millimeters.  
* Adjust the XY joints as necessary to ensure smooth motion.  
* After positioning correctly, tighten all screws carefully.  

---

### Verify Motion
* Slide the XY gantry along the X and Y axes by hand.  
* Ensure wheels roll smoothly without binding.  
* Check pulley alignment with belts — adjust if necessary before attaching the endstop.  

---

### Troubleshooting
* **Wheels bind or grind:** Check spacers, alignment, and V-slot cleanliness.  
* **XY gantry wobbles:** Ensure M5 locknuts are tight and spacers are correct length.  
* **Pulleys misaligned:** Re-position 20T pulleys before tensioning belts.  

---

### Measure and Cut the Gantry if Needed

1. Cut the X-axis extrusion to length (check your frame’s actual measurement).  
2. Tap new M5 threads on the cut ends.  
3. Proceed with **X+Z carriage assembly** as described in the next section of the manual.

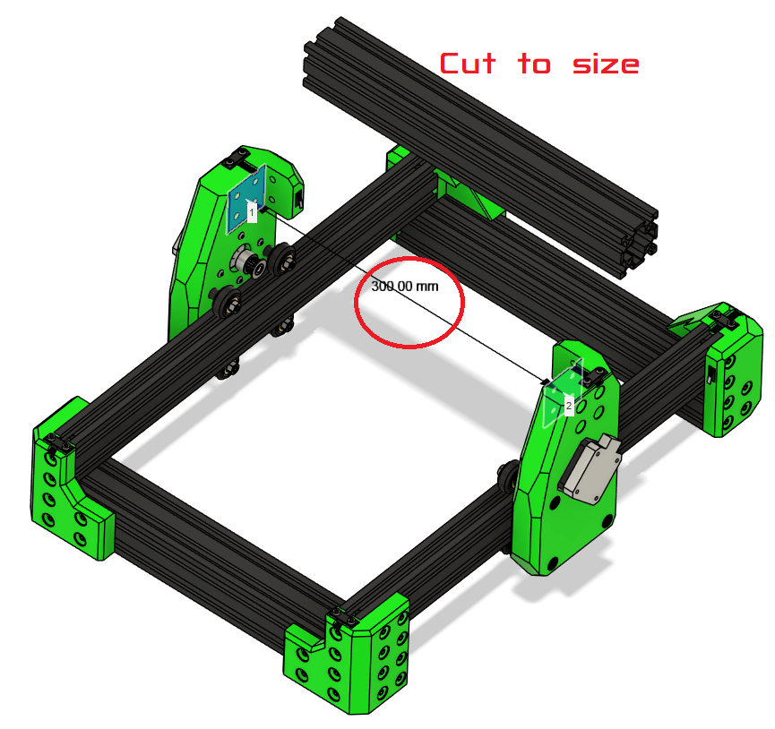
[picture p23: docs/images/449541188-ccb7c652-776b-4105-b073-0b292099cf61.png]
x_beam


!!! warning
    **DO NOT ATTACH THE GANTRY YET.** 
    It is done AFTER the carriage is attached.

---

## Final Checks

- Ensure frame is **square and rigid**.  
- Tighten bolts in blind joints. 

!!! warning
    Do **not press in the endstops** until wiring is complete. They are press-fit and may be difficult to remove afterward.

---

## Ready to Proceed?

Once you have completed the frame assembly, you are ready to finish the **Gantry Assembly**.

<p align="center">
  <a href="/EnderCNC/gantry" class="md-button md-button--primary">
    Continue to Final Gantry Assembly →
  </a>
</p>

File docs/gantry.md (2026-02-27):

# Final Gantry Assembly

## Mount Carriage to Gantry¶

  * Slide the carriage onto the 4040 frame extrusions by place the V-wheels into the V-slots.

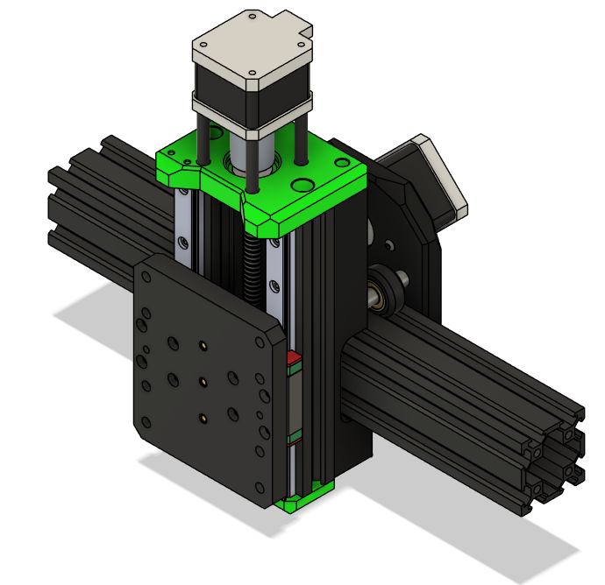
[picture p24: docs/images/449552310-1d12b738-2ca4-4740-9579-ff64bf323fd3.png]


!!! Warning
    Use gentle force and double-check alignment.

---

## Mount Assembly to Frame

### Parts Needed

| Qty  | Item | Source  | Notes |
|---|---|---|---|
| 8pc  | M5x30 BHSC | Buy | Frame bolts |



Attach bolts and the frame is complete



---

## Ready to Proceed?

You have now completed the frame assembly and ready to move on to the **Belts and Endstops**.

<p align="center">
  <a href="/EnderCNC/belts" class="md-button md-button--primary">
    Continue to Belts →
  </a>
</p>

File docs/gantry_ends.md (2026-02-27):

# Gantry

## Assemble the Gantry Brackets

!!! Note:
    Press fits and tolerances may vary slightly between frames.

## Parts Required

| Qty | Part | Source | Notes |
|-----|---|---|---|
| 4pc | Heatset | Buy | Voron Spec |
| 8pc | M5x45 SHSC | Ender3 | Remove shims from these |
| 8pc | M3x10 | BUY | |
| 8pc | 8mm Spacer (Printed or 5mm bore Alu) | Ender3 | |
| 8pc | V-Wheels | Ender3 | |
| 8pc | M5 Locknuts | Ender3 or BUY | |

#### Exploded View

XY_joints_heatsets

---

## Assembly Steps

### Add Heatsets to XY Joints

* Insert heatsets

XY_joints_heatsets

### Attach Nema17 Motors

* Remove stock pulley from motor with puller if not done already.
* Loosely attach the 20T pulleys to the X-motor if not done already.
* Add the M3x10 screws for securing the motor.

> **Tip:** Do not tighten fully yet — we will adjust alignment on the frame.

### Mount V-Wheels

* Slide the M5x45 screws through the XY joint mounting holes.  
* Place the 8mm spacers between the XY joint and the wheel mounts.  



### Add V-Wheels and Lock Nuts



---

## Ready to Proceed?

Once you have the gantry brackets assembled, continue to the next section to and begin the frame assembly.

<p align="center">
  <a href="/EnderCNC/frame" class="md-button md-button--primary">
    Continue to Frame Assembly →
  </a>
</p>

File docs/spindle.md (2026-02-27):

# Dremel Clamp

This chapter covers attaching your spindle or Dremel clamp.

---

## 1. Parts Required

| Qty  | Item | Source  | Notes |
|---|---|---|---|
| 4pc | M5x10 | Buy | Some may be spare from Ender3 |
| 1pc  | Dremel or Ø52–65mm Clamp | Buy/Printed | Depends on spindle choice |

## 2. Spindle / Dremel Clamp Installation

1. Choose the clamp compatible with your spindle/Dremel.  
2. Attach the clamp to the X carriage plate using M3 or M5 screws as per your design.  
3. Slide spindle or Dremel into the clamp.  
4. Adjust the height and secure tightly.  

Dremel Clamp

Spindle Clamp

---

### Tips

!!! tip
    If using a Dremel, you may need to slightly modify the printed clamp to fit snugly.

!!! warning
    Ensure the spindle cannot move during operation — any slip can damage the machine or workpiece.

---

---

## Ready to Proceed?

You have now completed tool attachment and ready to move on to the **Wiring and Electronics**.

<p align="center">
  <a href="/EnderCNC/wiring" class="md-button md-button--primary">
    Continue to Wiring and Electronics →
  </a>
</p>

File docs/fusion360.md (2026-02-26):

# Fusion 360 Klipperized post processor

Transform your Fusion 360 CAM workflow into a CNC-ready G-code workflow compatible with Klipper. This guide shows how to install and use the **Klipperized post processor** created for MPCNC and similar machines.

## Credits

Post processor by [Zergie/mpcnc_post_processor](https://github.com/Zergie/mpcnc_post_processor)– thanks for making Klipper integration possible!

## Installation

1. **Download the Post Processor**
   Download the `.cps` file from the GitHub repository linked above.

2. **Open Fusion 360**
   Navigate to the **Manufacture** workspace.

3. **Import the Post Processor**

   * Click **Post Process** in the toolbar.
   * Click the **folder icon** to select a post from the library.
   * Click **Import**.
   * Browse to your downloaded `.cps` file and click **Select**.

4. **Confirmation**
   Once imported, your post processor will appear in the list of available posts.

   

---

### Usage Notes

* **Do NOT select "upload and run"**
        This will immediately start your CNC job — risky if your setup isn’t ready.
* **Avoid setting G1 moves to G0 rapids at first**
        Travel moves will become extremely fast. Familiarize yourself with your machine before enabling.

   

 * Double-check toolpaths and clearance heights before running a job.

 * Always simulate in Fusion 360 first to prevent collisions.

---

## Recommended Workflow

1. Prepare your 3D model or 2D sketch.
2. Generate toolpaths using **2.5D or 3D milling operations**.
3. Select the **Klipperized post processor** for your CNC machine.
4. Export the G-code.
5. Load into your Klipper interface (e.g., Mainsail, Fluidd) and test with small movements first.

---

### Fusion360 Video Tutorial

Watch the video (https://www.youtube.com/watch?v=WxLeKf4OOfY)

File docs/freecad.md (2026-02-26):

# FreeCAD Overview

FreeCAD is a free, open-source parametric CAD software that lets you create and modify 3D models with precision. For the Ender 3 CNC project, FreeCAD is used to design custom parts, adjust dimensions for your frame, and generate models for 3D printing.

Whether you’re resizing a carriage plate, designing a clamp, or checking fitment, FreeCAD provides the flexibility to make your CNC build repeatable and accurate.

---

## Why FreeCAD?

* **Parametric Design:** Modify any dimension or feature without starting over.
* **Community Driven:** Active development and many tutorials.
* **Cross-Platform:** Runs on Linux, Windows, and macOS.
* **File Export Options:** Supports STEP, STL, DXF, and more — ideal for CNC and 3D printing workflows.

---

## Recommended Workflows

### 1. Adjust Existing Parts

Many Ender3CNC components are already designed in FreeCAD. You can open the `.FCStd` files and tweak dimensions:

* Carriage spacing
* Clamp thickness
* Pulley clearance
* Mounting hole positions

**Tip:** Always save a backup of the original before making changes.

---

### 2. Create Custom Parts

Need a new part for your CNC? FreeCAD lets you:

1. Sketch 2D geometry on a plane.
2. Extrude, pad, or cut features to create a 3D model.
3. Add mounting holes, fillets, or chamfers for strength and fit.
4. Export to `.STL` for 3D printing or `.STEP` for CNC machining.

---

### 3. Verify Fit and Assembly

Use FreeCAD’s **Assembly Workbench** or simply check parts visually:

* Ensure rails and carriages align.
* Confirm belt paths are unobstructed.
* Check that the Z probe or endstops have proper clearance.

---

## Recommended Settings for Ender3CNC Parts

* Units: **Millimeters**
* Snap increments: **0.1 mm** for fine adjustments
* Export resolution: High for smooth 3D printing surfaces

---

### FreeCAD Video Tutorial

If you add the mkdocs-video plugin, you can embed a demo video of adjusting parts:

FreeCAD CAM Tutorial (https://www.youtube.com/watch?v=0VAIXvHTKVY)

---

## Resources

* [FreeCAD Official Website](https://www.freecadweb.org)
* [FreeCAD Forum](https://forum.freecadweb.org)
* [FreeCAD Tutorials on YouTube](https://www.youtube.com/results?search_query=freecad+tutorial)

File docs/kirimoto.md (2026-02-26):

# Kiri:Moto CAM & Workflow

Kiri:Moto is a free, browser-based CAM (Computer-Aided Manufacturing) and toolpath generator designed for desktop CNC machines. It works with 2D, 2.5D, and 3D operations, making it a perfect companion for your Ender 3 CNC build.

---

## Why Kiri:Moto?

* Browser-based – no heavy installation required.
* Supports milling, carving, and drawing operations.
* Compatible with GRBL, Marlin, and Klipper.
* Familiar interface for makers already comfortable with 3D printing.

---

## Getting Started

1. Open [Kiri:Moto](https://grid.space/kiri) in a modern browser.
2. Load your 3D model (`.STL`, `.OBJ`, `.SVG` for 2D operations).
3. Set your **machine parameters**:
   * CNC type: “Cartesian”
   * Bed size: Match your Ender 3 build
   * Tool diameter: Match your spindle or endmill
4. Configure the **workspace and stock**:
   * Define material dimensions
   * Set origin (bottom-left or center of stock)
5. Choose your operation:
   * **2D pockets, traces, or cuts**
   * **3D carving**
   * **3D adaptive clearing** for larger parts

---

## Workflow Tips

* **Link stock and model** – Ensure the model is positioned relative to the material to avoid collisions.  
* **Work Coordinate System (WCS)** – Use the coordinate system to define origin and orientation for each part.  
* **Output** – Select your post-processor:
  * Klipper (`.gcode`)
  * GRBL (`.nc`)
  * Marlin (`.gcode`)
* **Simulate** – Always check the toolpath simulation before milling.

---

## Integration with Ender3CNC

* Kiri:Moto output works directly with Klipper and GRBL-based workflows.
* Toolpaths generated in Kiri:Moto can be sent to your Raspberry Pi or Ubuntu laptop running your CNC controller.
* Supports **dual Y-axis operations**, ensuring synchronized movement across your upgraded Ender 3 CNC.

---

### Tip

For complex parts, break your workflow into multiple operations:
* Roughing pass → Finishing pass → Engraving or drilling
* This reduces load on your motors and improves surface finish.

---

### Learning Video

Watch the video (https://www.youtube.com/watch?v=nQUvXOjDib4)

---

## Resources

* [Kiri:Moto Official Documentation](https://grid.space/kiri/help)
* [Kiri:Moto on GitHub](https://github.com/gridspace/kiri)
* [Community Forum](https://forum.grid.space/c/kiri/)

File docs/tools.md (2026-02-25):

# Tools & Equipment Required

Before beginning the mechanical conversion, ensure you have the following tools and equipment available.

This build involves modifying aluminum extrusions, cutting threads, aligning structural components, and installing threaded inserts. Proper tools directly impact final rigidity and alignment accuracy.

---

## Core Requirements

* **Ability to cut, drill and tap aluminum extrusions**
  A miter saw with a non-ferrous blade, bandsaw, or hacksaw with fine tooth blade will work. Clean, square cuts are critical for frame alignment. We will go through this process.

* **Linux machine running Klipper (optional)**
    * Raspberry Pi (recommended), or
    * Old laptop running Ubuntu or similar
      Required only if using the Klipper control setup.

* **Spindle or Rotary Tool (Dremel-style)**
  Ensure compatibility with printed clamps before purchasing.
  Check mounting diameter and weight.

!!! tip "Recommended Approach"
    Perform frame assembly on a flat, rigid surface.
    Surface flatness directly affects squareness and long-term dimensional accuracy.

---

## Tools

| Tool | Purpose |
| --- | --- |
| Hex Drivers (Allen keys) | Assembly and frame tightening  |
| M5 Tap | Cutting extrusion end threads  |
| Drill + Bits | Blind joint access holes |
| Blind Joint Drilling Jig | Ensures correct hole placement |
| Pulley Extraction Tool | Removing press-fit pulleys |
| Heat Set Insert Tool | Installing threaded inserts |
| Machinist Square | Ensuring frame alignment |
| Hack saw or Band saw | Cutting Z rail extrusion mount |

---

### Hex Drivers
Most builders received these with their Ender 3. These are not the highest quality and may round off if not careful. 

!!! tip
    For improved ergonomics and torque control, consider printed handles such as: [Hex Key EZ handles](https://www.printables.com/model/966972-hex-key-ez-handles)

Hex Drivers

### M5 Tap

Used to cut internal threads in aluminum extrusion ends.

Recommendations:

* Use proper cutting oil (e.g., Tap Magic or similar)
* Advance slowly and back out periodically to clear chips
* Clean the tap between holes
* Keep the tap perpendicular to prevent cross-threading

!!! tip
    Thread alignment directly affects joint strength and frame squareness.

M5 Tap

### Drill for Blind Joints

Blind joints allow you to secure two extrusions without drilling completely through both members.

You will drill an access hole that allows a hex driver to reach the internal fastener.

!!! tip "Ensuring correct placement and consistent results"
    [2020 Extrusion Blind Joint Drilling Jig](https://www.printables.com/model/815359-2020-extrusion-blind-joint-drilling-jig)

Accuracy here prevents misalignment and frame twist.

Blind Joint Example

---

### Pulley Extraction Tool

Stepper motor pulleys are often press-fit and difficult to remove without damage.

If you do not have a pulley puller, you can print a [Pulley Extractor](https://www.printables.com/model/230013-press-fit-pulley-extractor-for-nema-17) or cut them off (not recommended).

!!! tip
    Avoid prying against the motor housing — this can permanently damage bearings.

Pulley Extractor

---

### Heat Set Insert Tool

A soldering iron with appropriate tip is required for installing heat set threaded inserts into printed components.

Best practices:

* Use temperature appropriate for insert size
* Apply steady downward pressure
* Ensure insert is perpendicular during insertion
* Allow part to cool fully before applying torque

Proper insert installation significantly improves mechanical durability.

Heat Set Insert Tool

### Saw

The stock Ender 3 top horizontal extrusion will be cut and repurposed to form the dual Z-axis vertical rails.

* Miter saw with non-ferrous blade (preferred)
* Bandsaw with fine-tooth blade
* Hacksaw (acceptable with care)

!!! Tip "Making ends square"
    Use a router to make sure ends of extrusion are square and the same length.

router fixing extrusion ends

---

## Optional but Recommended

* Metric ruler (for verifying cut lengths)
* Thread locker (medium strength)
* Deburring tool or file
* Clamps (for holding extrusions during drilling)
* Dial indicator (for bed leveling and advanced alignment verification)

---

## Ready to Proceed?

Once you have the required tools, continue to the next section to review required hardware and the Bill of Materials.

<p align="center">
  <a href="/EnderCNC/hardware" class="md-button md-button--primary">
    Continue to Hardware & BOM →
  </a>
</p>

---

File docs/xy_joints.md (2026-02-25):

# XY Joints

### !! Note: These instructions are specific to the Ender 3 PRO CNC conversion. Pressfits and tolerances may vary slightly between frames.

## Parts Required

| Qty | Part | Source | Notes |
|-----|---|---|---|
| 8pc | M5x45 SHSC | Ender3 | Remove shims from these |
| 8pc | M3x10 | BUY | |
| 8pc | 8mm Spacer (Printed or 5mm bore Alu) | BUY | |
| 8pc | V-Wheels | Ender3 | |
| 8pc | M5 Locknuts | Ender3 or BUY | |

---

## Assembly Steps

### 1️⃣ Pre-assemble XY Joints
* Loosely attach the 20T pulleys to the X-motor plate if not done already.  
* Slide the M5x45 screws through the XY joint mounting holes.  
* Place the 8mm spacers between the XY joint and the wheel mounts.  
* Add the M3x10 screws for securing the top/bottom brackets.  

> **Tip:** Do not tighten fully yet — we will adjust alignment on the frame.

XY_joints_heatsets

---

### 2️⃣ Mount XY Joints to Frame
* Slide the XY joints onto the 2020 frame extrusions.  
* Place the bottom V-wheels into the V-slot.  
* Loosely add M5 locknuts to the bottom wheels.  
* Tilt the XY joint slightly to insert the top wheels into the V-slot.  
* Wiggle the assembly so the top screws pop into place.  

> **Warning:** The XY joints are pressfit in some positions; force gently and double-check alignment.

x_beam

---

### 3️⃣ Check Alignment
* Measure the distance between the X extrusion mounting points — Ender 3 frames may vary by ± a few millimeters.  
* Adjust the XY joints as necessary to ensure smooth motion.  
* After positioning correctly, tighten all screws carefully.  

> **Tip:** You can temporarily remove the 2040 extrusions from the frame to slide XY joints on if needed. You may need to re-square the frame afterward.

---

### 4️⃣ Verify Motion
* Slide the XY gantry along the X and Y axes by hand.  
* Ensure wheels roll smoothly without binding.  
* Check pulley alignment with belts — adjust if necessary before attaching the endstop.  

---

### 5️⃣ Optional: Add Endstop Later
* Do not press in the X-endstop yet.  
* Only mount the endstop after confirming XY motion and belt alignment.  
* The buffer attachment is only needed if using vacuum or splashguard.



---

### Troubleshooting
* **Wheels bind or grind:** Check spacers, alignment, and V-slot cleanliness.  
* **XY gantry wobbles:** Ensure M5 locknuts are tight and spacers are correct length.  
* **Pulleys misaligned:** Re-position 20T pulleys before tensioning belts.  

---

### Next Steps
Once XY joints are installed and verified:

1. Cut the X-axis extrusion to length (check your frame’s actual measurement).  
2. Tap new M5 threads on the cut ends.  
3. Proceed with **X+Z carriage assembly** as described in the next section of the manual.

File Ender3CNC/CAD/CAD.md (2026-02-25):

# CAD

Current Fustion f3z and FreeCAD step files

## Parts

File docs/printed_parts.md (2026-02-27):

# 3D Printed Parts

## Print settings

* PLA
* 5 walls
* 5 top/bottom layers
* 40% gyroid infill

**Print orientation to avoid supports:**

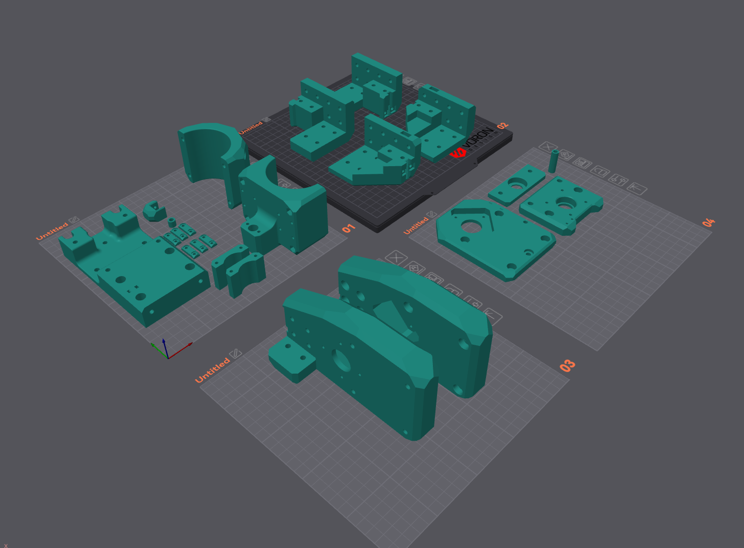
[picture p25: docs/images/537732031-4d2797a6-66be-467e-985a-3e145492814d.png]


## Other parts 

- [2020 Extrusion Blind Joint Through hole Jig](https://www.printables.com/model/815359-2020-extrusion-blind-joint-drilling-jig)
- [Press-fit pulley Extractor](https://www.printables.com/model/230013-press-fit-pulley-extractor-for-nema-17)
- Spacers
- [Clamps](https://www.printables.com/model/125781-clamp-holder-for-a-3018-cnc-milling-engraving-mach)
- Endstops
  - [X & Y Endstops](https://www.printables.com/model/1365912-e3cnc-belt-clamps-with-original-endstops)
  - [Z Endstop](https://www.printables.com/model/1605131-e3cnc-z-endstop-mod)
- [Z probe](https://www.printables.com/model/1372537-e3cnc-limit-switch-z-probe-tool-height-sensor)
- [Marker tool](https://www.printables.com/model/1610808-e3cnc-pen-holder)
- [Electronics Enclosure](https://www.printables.com/model/226631-external-electronics-box-for-ender-3-pro)
- [Parts Organizer](https://www.printables.com/model/84834-parametric-small-parts-organizer-tray-for-disassem)

### [Through hole Jig](https://www.printables.com/model/815359-2020-extrusion-blind-joint-drilling-jig)



### [Pully Extractor](https://www.printables.com/model/230013-press-fit-pulley-extractor-for-nema-17)

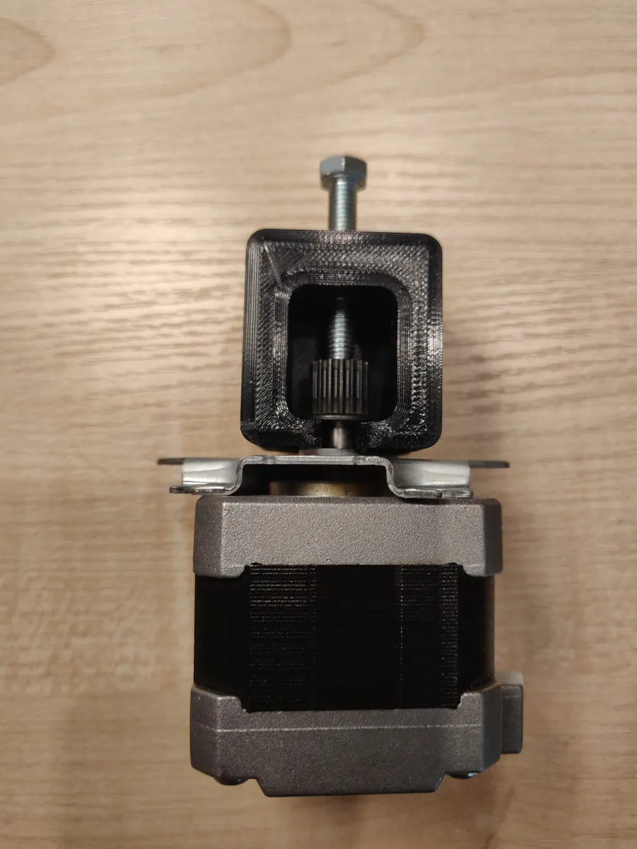
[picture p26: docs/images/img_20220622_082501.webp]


### [X & Y Endstops](https://www.printables.com/model/1365912-e3cnc-belt-clamps-with-original-endstops)

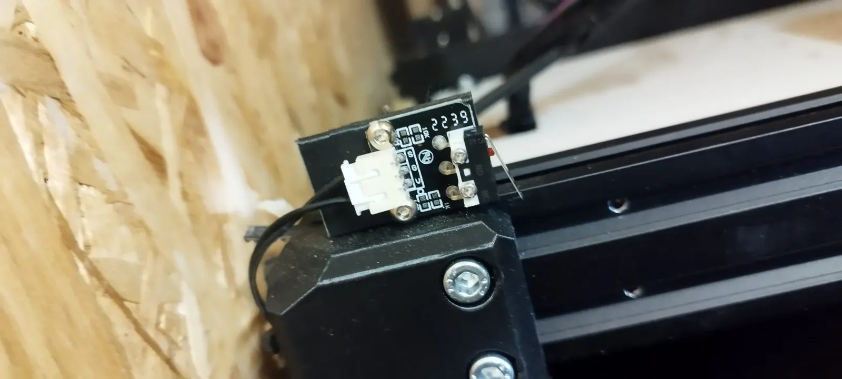
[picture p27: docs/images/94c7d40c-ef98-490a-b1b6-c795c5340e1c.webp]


### [Z Endstop](https://www.printables.com/model/1605131-e3cnc-z-endstop-mod)

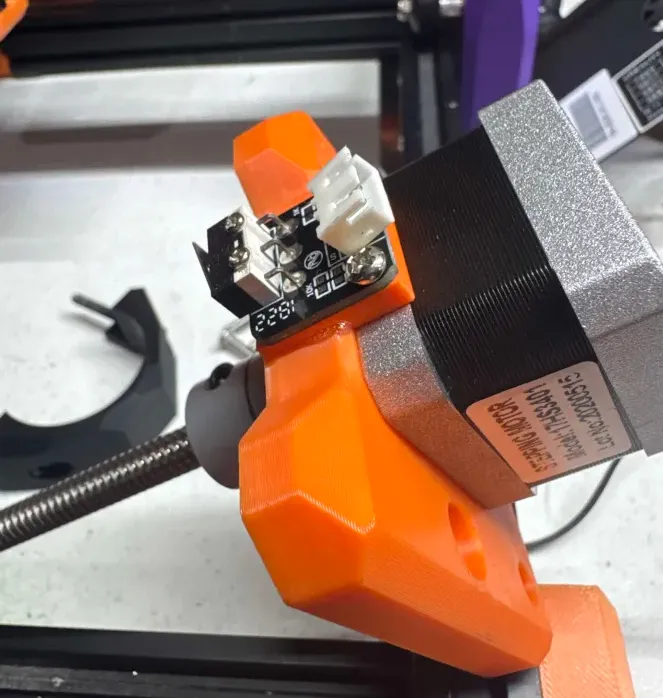
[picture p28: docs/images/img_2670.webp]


### [Z probe](https://www.printables.com/model/1372537-e3cnc-limit-switch-z-probe-tool-height-sensor)

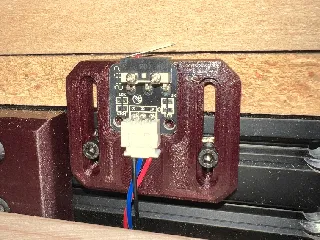
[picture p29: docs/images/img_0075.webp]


### [Clamps](https://www.printables.com/model/125781-clamp-holder-for-a-3018-cnc-milling-engraving-mach)

!!! warning
    This clamp needs to be modified.

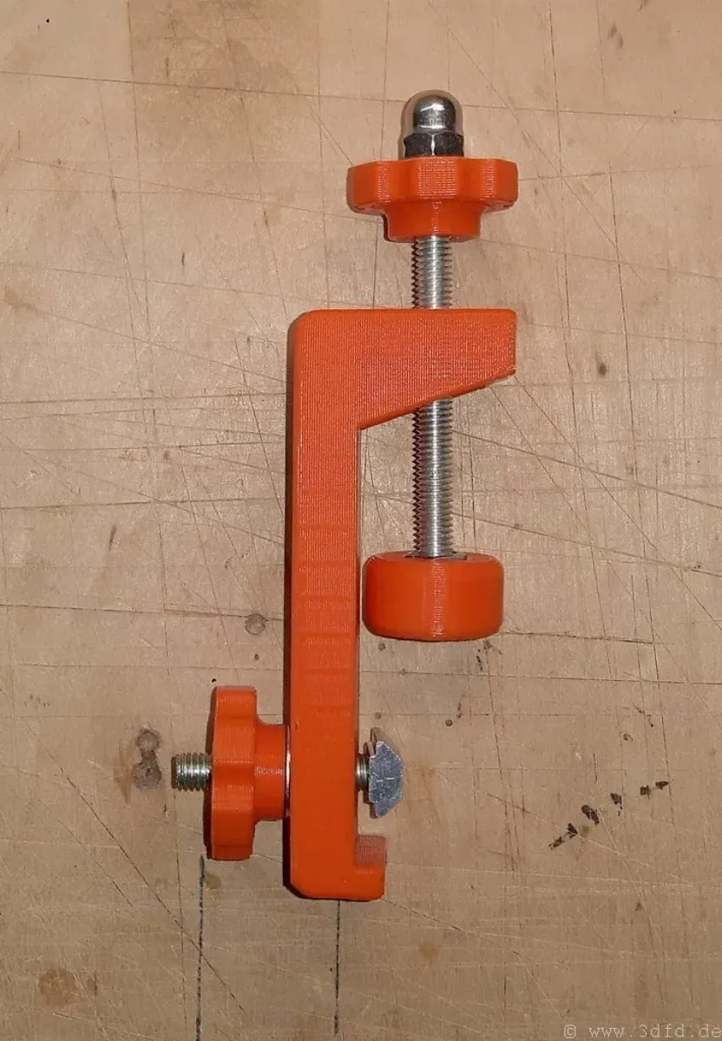
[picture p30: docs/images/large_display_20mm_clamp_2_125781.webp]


### [Pen holder](https://www.printables.com/model/1610808-e3cnc-pen-holder)

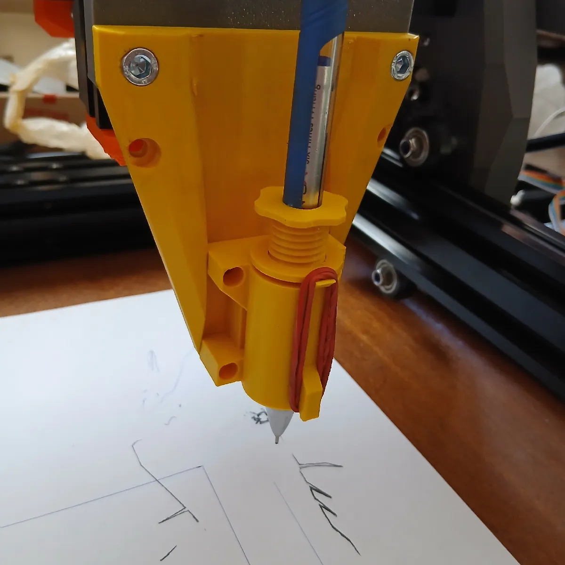
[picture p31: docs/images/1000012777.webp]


### [Electronics Enclosure](https://www.printables.com/model/226631-external-electronics-box-for-ender-3-pro)

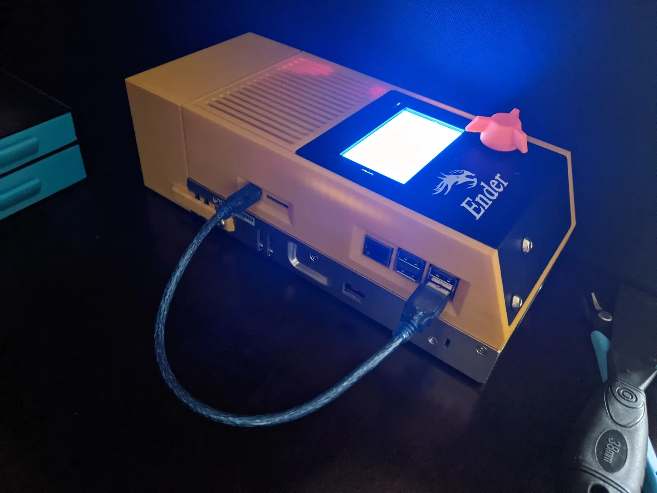
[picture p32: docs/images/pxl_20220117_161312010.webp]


### [Parts Organizer](https://www.printables.com/model/84834-parametric-small-parts-organizer-tray-for-disassem)



---

## Ready to Proceed?

After completing these steps, you are ready to **Disassemble your Ender 3**.

<p align="center">
  <a href="/EnderCNC/disassembly" class="md-button md-button--primary">
    Continue to Ender Disassembly →
  </a>
</p>

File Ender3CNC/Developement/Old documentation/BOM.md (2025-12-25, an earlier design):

# Bill of Materials (BOM)

## Notes
This is a reference BOM from my own build and CAD. I might have counted wrong. If you find any issues please let me know.

I've tried to keep the BOM parts as close as possible to a Voron 3D Printer build in hopes people already have some of the BOM already.

---

## Parts from Ender 3 Pro

## !NOTE! Some Ender 3's might be sligthly different in what hardware was used in what year/make. So please dont follow it 100% blindly. 

### You can re-use 3 limit switches from the Ender 3, but you need to cut them off the PCB's and you'll still be missing 1, so you need to order AT LEAST 1 more.
### You can re-use 2 belt lengts from the Ender 3, but you still need one more ~500mm lenght, so better to just buy get 2-3 meters to have some spare too.  

| Quantity | Part Description | Notes |
|---|---|---|
| **M5 Screws** |
| 10x | M5x30 button head | |
| 16x | M5x45 bolts | From E3P frame (remove shims if possible) |
| 4x | M5x8 | |
| 1x | M5x65 | Middle lower X axis wheel (optional) |
| All | M5 nuts | From your Ender 3 |
| **M4 Screws** |
| 2x | M4x20 | |
| 2x | M4x16 | |
| 2x | M4x10 | Includes 2x M4 t-nuts |
| **M3 Screws** |
| 6x | M3x10 | |
| 11x | M3x10 | Additional |
| 4x | M3x40 | |
| 12x | M3x6 | |
| **Bearings** |
| 2x | 688 bearings | If your E3P has these; otherwise buy 608ZZ |

---

## Parts to Purchase

| Quantity | Part Description | Specifications | Notes |
|---|---|---|---|
| **Motion Components** |
| 3x | GT2 belts | ~500mm length each, 6mm width | Buy 3-5 meter roll on AliExpress |
| 3x | GT2 pulleys | 20T, 6mm width, 5mm bore | |
| 2x | MGN12H linear rails | 150mm length | 1 carriage per rail |
| 2x | 608ZZ bearings | 8x22x7mm | Or use 688 from Ender 3 |
| **Electronics** |
| 4x | D2F-L Microswitch | Limit switch | Get 10 pack on AliExpress |
| **Fasteners** |
| ~20x | M3 T-nuts | For 2020 extrusion | Sliding or standard t-nuts |
| ~40x | M5 T-nuts | For 2020 extrusion | Sliding or standard t-nuts |
| 10x | M5 locknuts | Hex nuts | |
| ~70x | M5x16 button head screws | | |
| 22x | M3x10 screws | Not countersunk | |
| 12x | M3x8 SHCS | Socket head cap screws | |
| **Hardware** |
| 30x | Heat set inserts | M3x4x5mm | Voron spec |
| 4x | M5 shims | OD 10mm, ID 5mm, 1mm thick | |

---

## Optional Upgrades

| Quantity | Part Description | Specifications | Purpose |
|---|---|---|---|
| 8x | Aluminum spacers | 5mm ID x 8mm OD x 8mm length | Replaces printed Y axis wheel spacers |

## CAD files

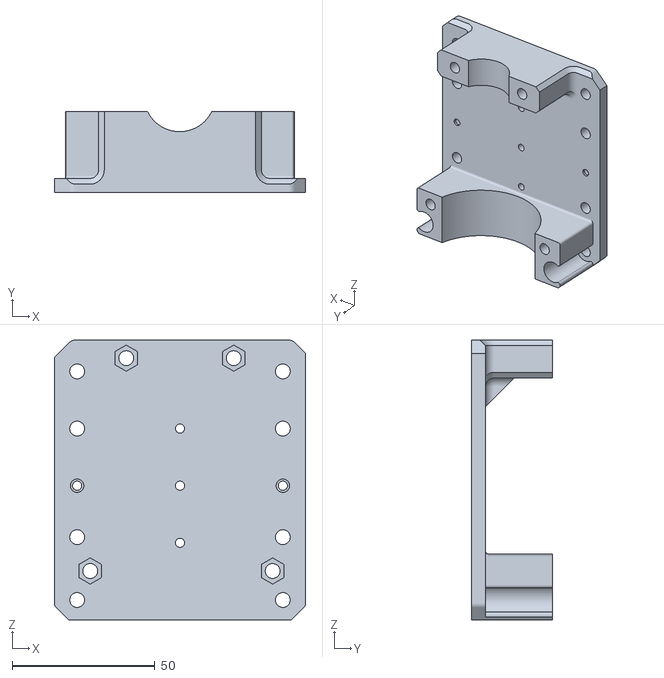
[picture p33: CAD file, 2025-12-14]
Ender3CNC/Developement/Faceplate Dremel mod/dremel_main_body_faceplate_remix.stl
88.0 x 28.5 x 98.0

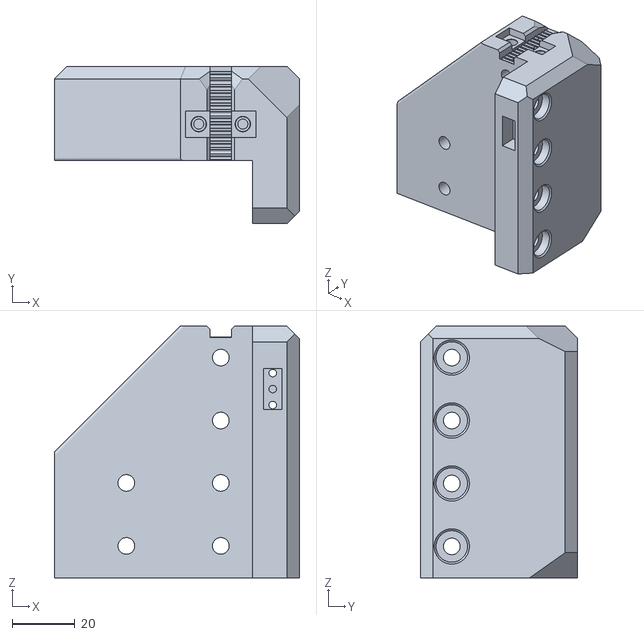
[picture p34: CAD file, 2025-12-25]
Ender3CNC/Developement/2040_frame_mod/back_right_corner_2040.stl
77.8 x 50.0 x 80.0

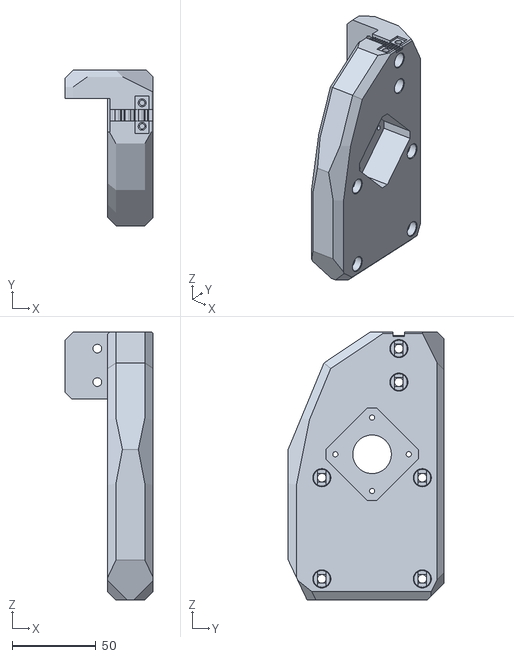
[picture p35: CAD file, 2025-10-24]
Ender3CNC/Developement/ender3nonpro stl/non_pro_XY-R.stl
52.8 x 93.0 x 160.0

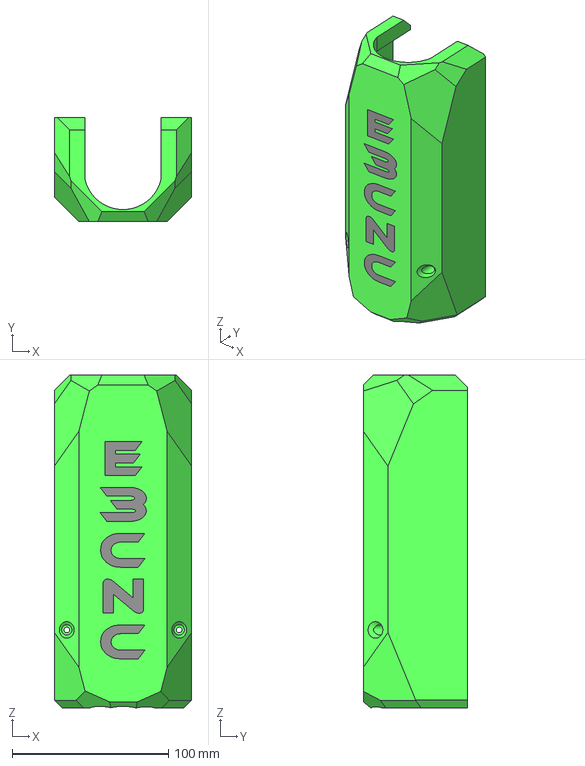
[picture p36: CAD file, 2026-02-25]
Ender3CNC/Developement/Faceplate Dremel mod/Faceplate_step_multicolor.step
88.0 x 66.7 x 213.3 mm

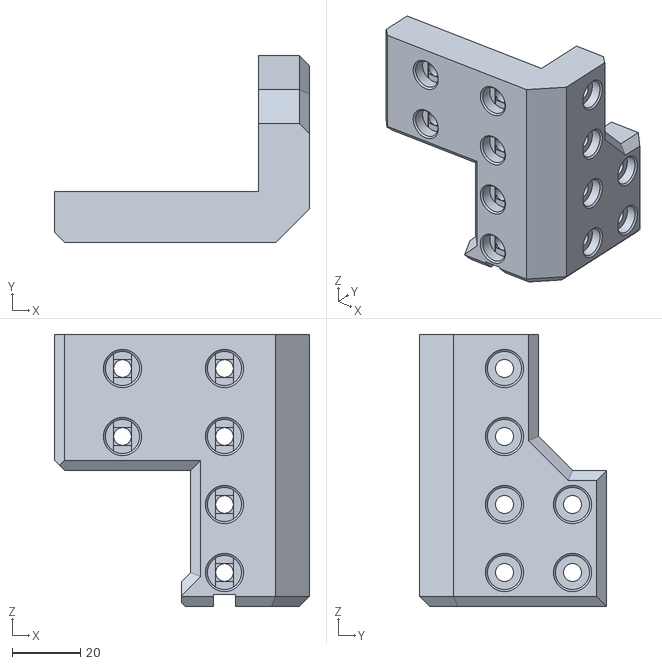
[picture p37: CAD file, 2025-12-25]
Ender3CNC/Developement/2040_frame_mod/front_left_corner_2040.stl
75.0 x 55.0 x 80.0

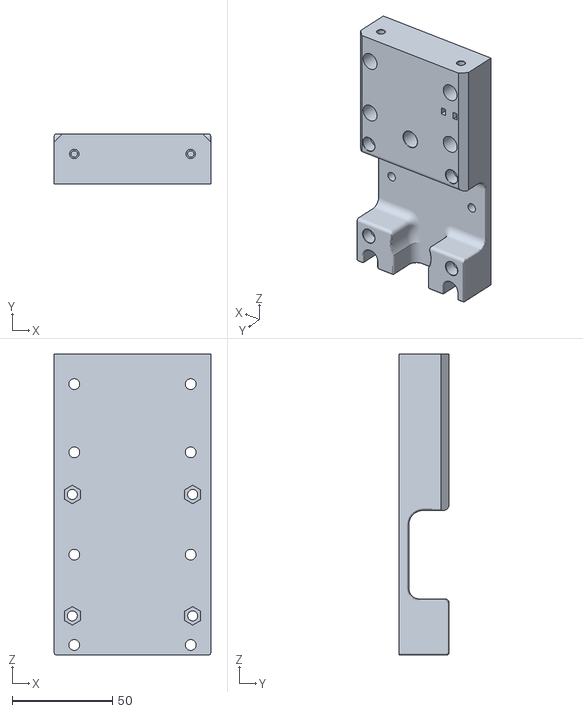
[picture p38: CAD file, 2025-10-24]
Ender3CNC/Developement/ender3nonpro stl/non_pro_Z_axis.stl
78.0 x 25.0 x 150.0

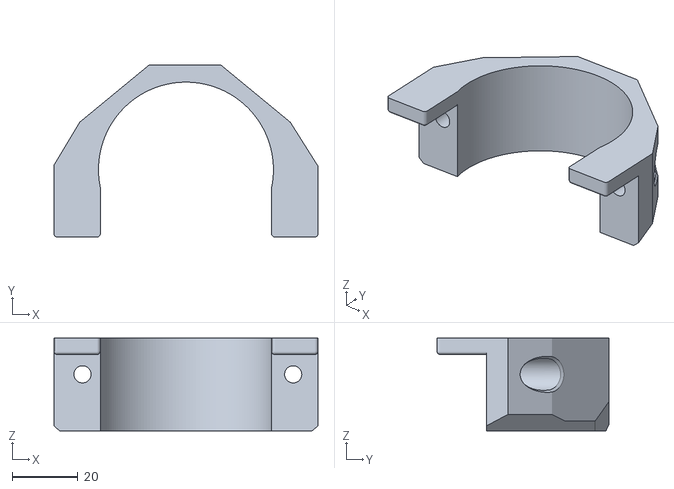
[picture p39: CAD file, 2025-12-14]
Ender3CNC/Developement/Faceplate Dremel mod/dremel_top_clamp_faceplate_remix.stl
80.0 x 52.1 x 28.2

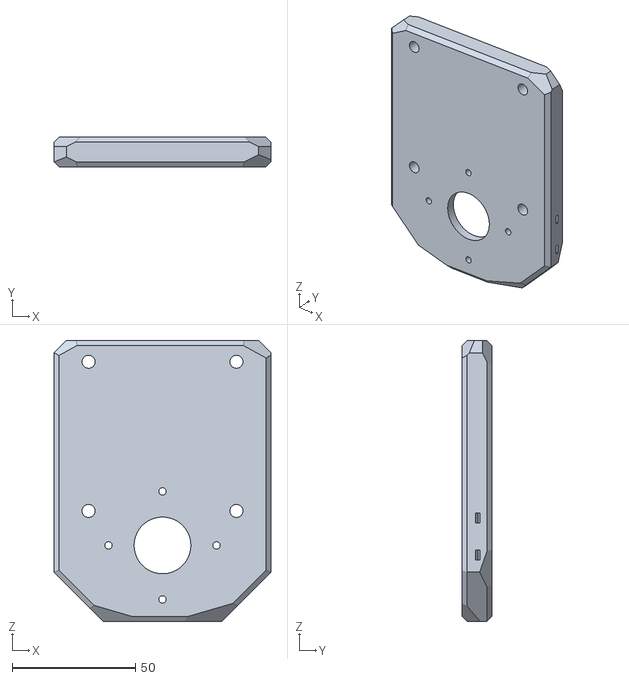
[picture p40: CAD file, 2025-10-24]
Ender3CNC/Developement/ender3nonpro stl/non_pro_X_motor.stl
88.0 x 12.0 x 114.0

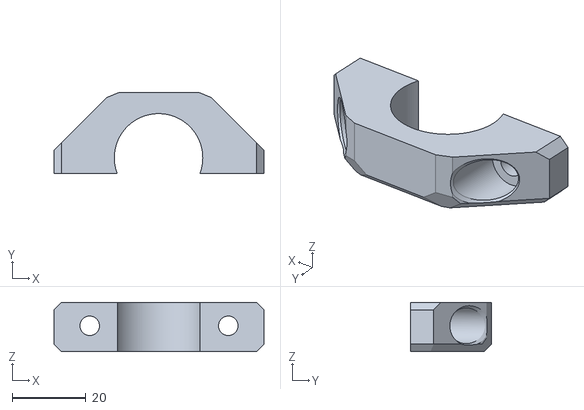
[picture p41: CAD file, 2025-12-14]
Ender3CNC/Developement/Faceplate Dremel mod/dremel_bottom_clamp_faceplate_remix.stl
57.0 x 22.1 x 13.4

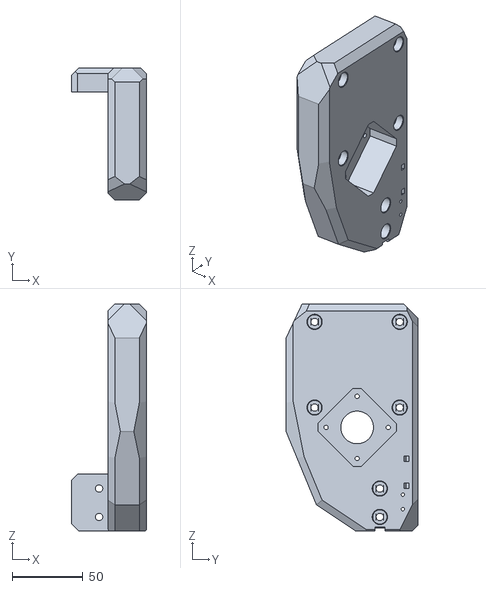
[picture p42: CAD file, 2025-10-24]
Ender3CNC/Developement/ender3nonpro stl/non_pro_XY-L.stl
52.8 x 93.0 x 160.0

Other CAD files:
Ender3CNC/Developement/2040_frame_mod/back_left_corner_2040.stl
Ender3CNC/Developement/2040_frame_mod/front_right_corner_2040.stl
Ender3CNC/Developement/2040_frame_mod/corner_2040_mod_CAD.f3d
Ender3CNC/Developement/Faceplate Dremel mod/Beefy_Dremel_Clamp_REMIX_FACEPLATE.f3d
Ender3CNC/Developement/ender3nonpro stl/Ender3_NON_PRO_X_gantry.f3d

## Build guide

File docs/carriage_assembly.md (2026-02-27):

# Z Carriage Assembly

This chapter focuses on the Z-axis carriage, bearings, and coupler alignment.

---

## Assemble the X+Z Carriage

1. Cut Ender3 2020 extrusions to 150mm x2.  
2. Tap M5 threads in **both ends** of the 150mm extrusions.  
3. Press in bearings if not already done.  
4. Loosely attach:
   - Z motor coupler
   - X motor pulley (20T)
5. Attach both motors to their plates.  
6. Assemble the 2020 extrusions as square and parallel as possible.  
7. Mount the X motor carriage to the ZX carriage with wheels and spacers.  
8. Attach the Z bottom bearing plate and Z motor plate.  
9. Mount the MGN12 rails with carriages to the 2020 extrusions:
   - Use a printed **MGN12->2020 alignment tool** to ensure straight rails.  
   - Rails can slide into cutouts if slightly too long (max 4mm overhang).  
10. Attach Z leadscrew nut to Z carriage.  
11. Mount Z carriage to MGN12H carriages:
    - Slide up and down to check for binding. Adjust rails if necessary.  
12. Cut leadscrew to size (~180mm), double-check with your setup.  
13. Screw leadscrew from bottom bearing to Z motor coupler and secure.  
14. Slide the X+Z assembly on the previously cut X extrusion.

## Parts Required

| Qty | Item | Source | Notes |
|-----|---|---|---|
| 1pc | Z Carriage Plate | Printed | Heatset inserts required |
| 2pc | M5 Locknuts | Buy | Press-fit into plate |
| 2pc | M5x16 BHSC | Buy | Z-axis carriage attachment |
| 1pc | Leadscrew Nut | Buy | M5 threaded for Z |
| 2pc | MGN12H Carriages | Buy | For smooth linear motion |

## Bearing Choice

### If you dont have 608Z use the F688Z from the Ender 3 Pro X axis tensioner. 
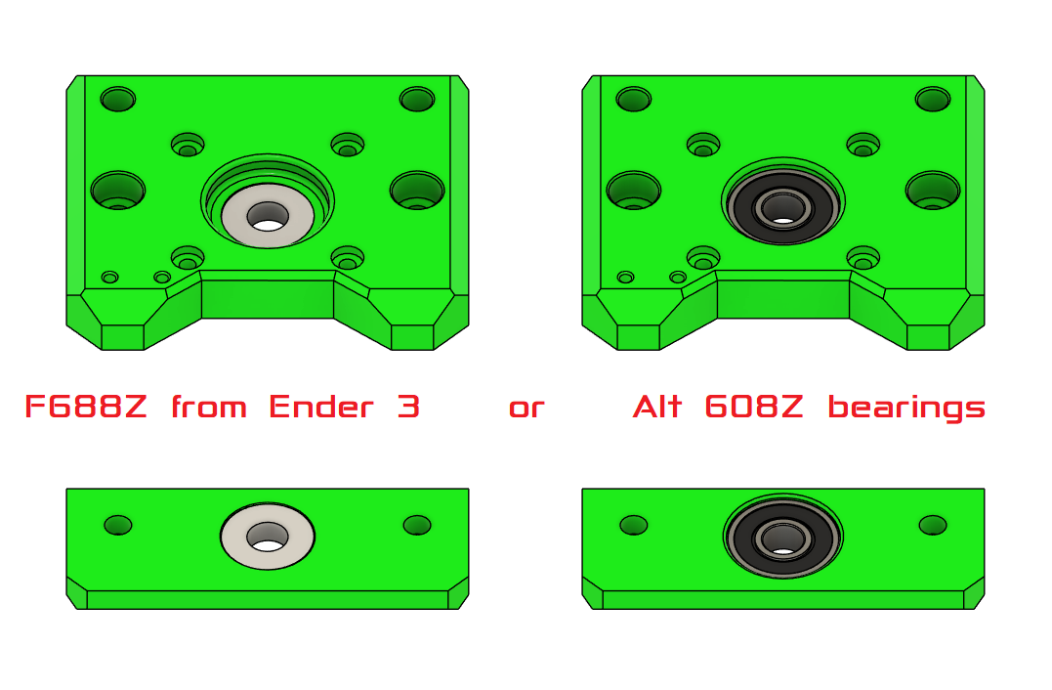
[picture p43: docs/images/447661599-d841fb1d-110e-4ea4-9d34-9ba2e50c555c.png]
bearing_choice


---

## Backplate Assembly

1. Insert heatset inserts into Z carriage plate.  
2. Press-fit M5 locknuts into their designated holes.  

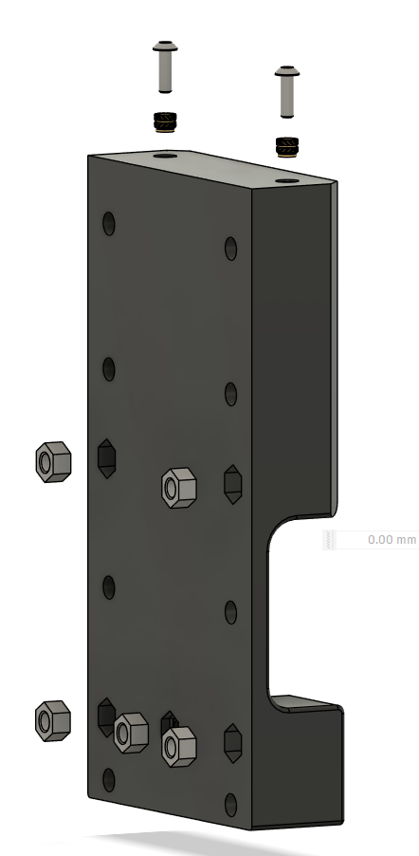
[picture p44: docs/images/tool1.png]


3. Attach M5 Locknuts and Bolts to Z carriage plate.
  
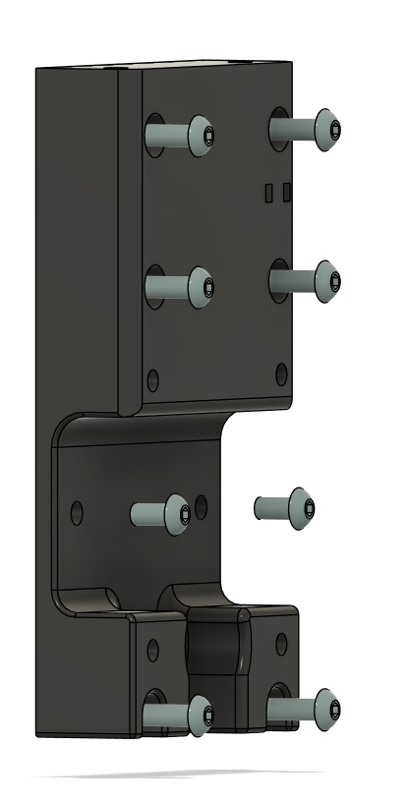
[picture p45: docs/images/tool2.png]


4. Assemble X gantry motor plate

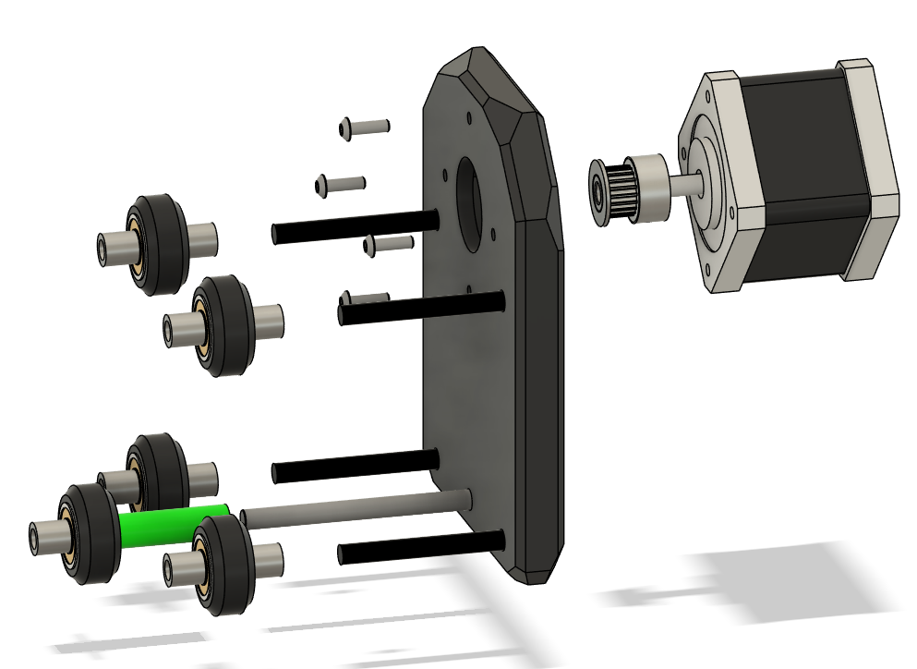
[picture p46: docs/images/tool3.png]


5. Attach X gantry motor plate to xz gantry plate

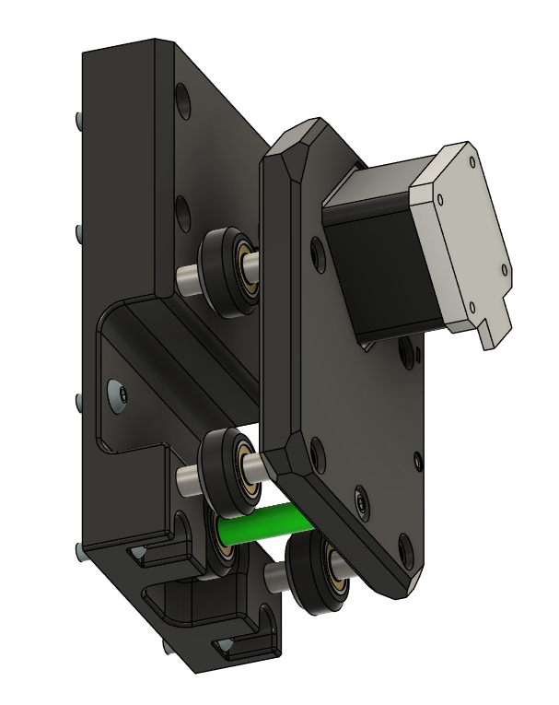
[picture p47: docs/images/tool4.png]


---

## Frontplate 

1. Attach motor to top plate
2. Loosely attach coupler to Z motor shaft.  

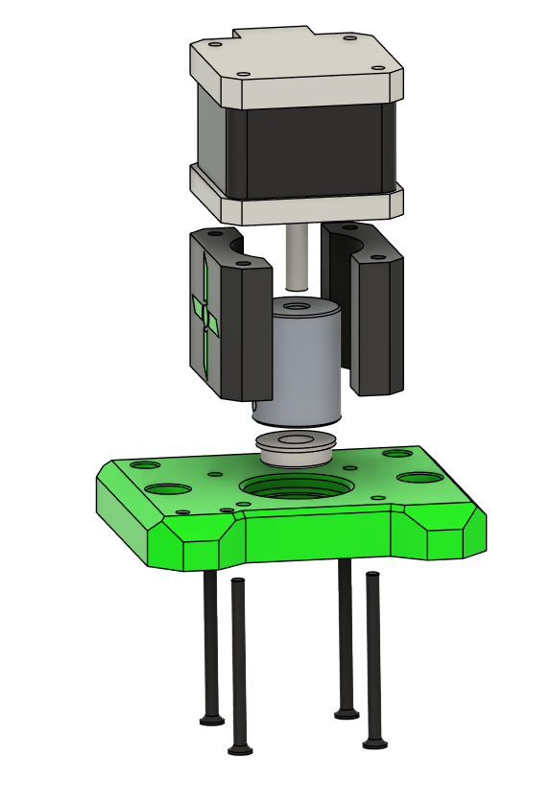
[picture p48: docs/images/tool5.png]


1. Attach bottom plate to extrusion
2. Attach 2020 Extrusion to rails  
3. Attach MGN12H carriages to the 2020 extrusions if not already done.  
4. Slide Z carriage onto MGN12H carriages.  

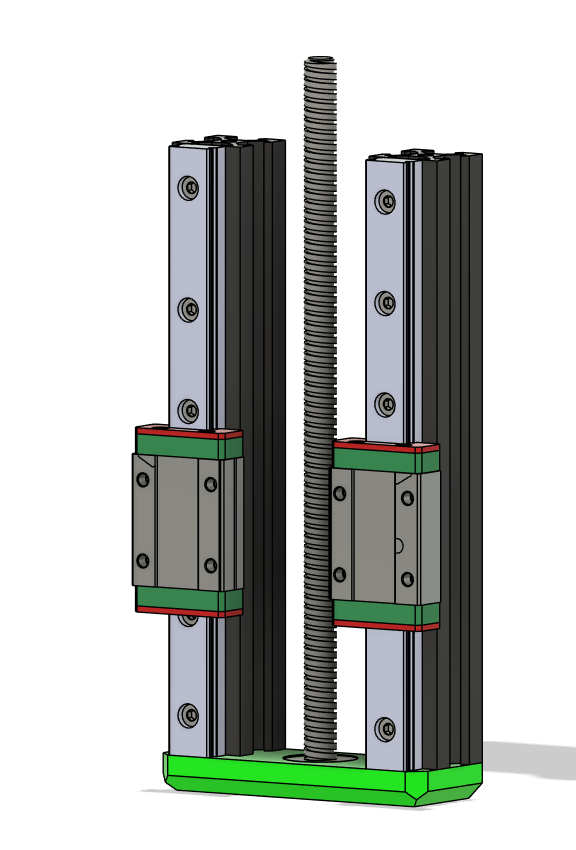
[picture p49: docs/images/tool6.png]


5. Attach leadscrew nut to Z carriage.  
6. Attach z top to extrusion by inserting leadscrew from bottom bearing to coupler:
   - Ensure smooth rotation by hand.  
   - Adjust alignment if carriage binds on rails.

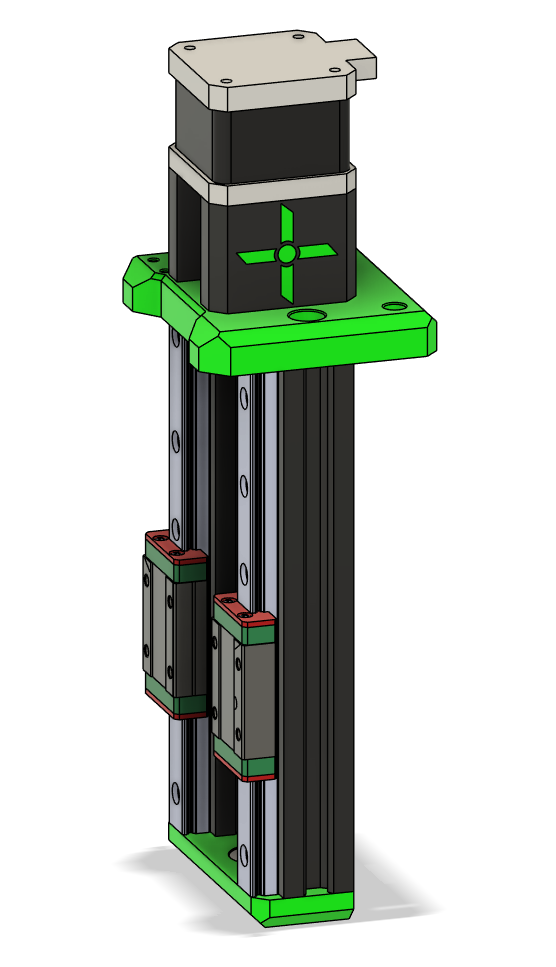
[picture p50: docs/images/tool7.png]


---

## Assembly

Attach Backplate to Extrusion and top screws

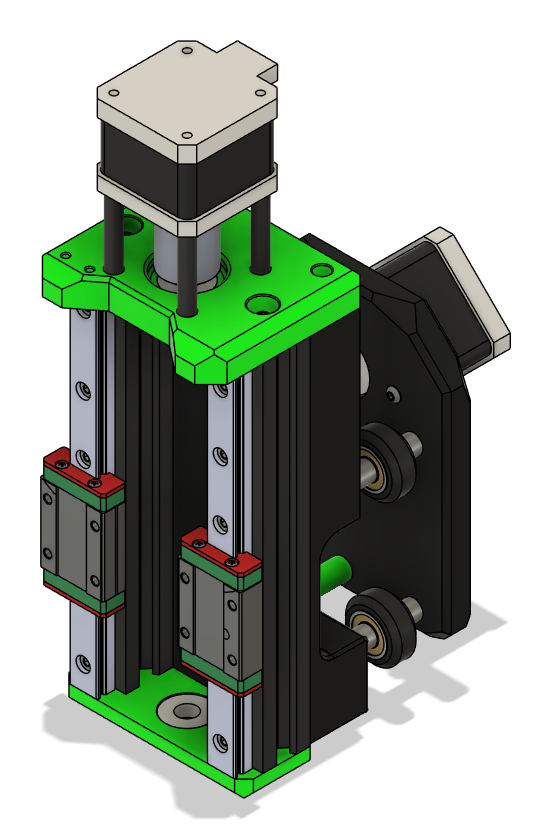
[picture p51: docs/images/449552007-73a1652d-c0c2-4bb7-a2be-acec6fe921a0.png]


---

## Tips & Tricks

!!! tip
    Test the Z-axis movement **manually** before wiring the motors.  
    Smooth motion now saves time troubleshooting later.

!!! warning
    Avoid forcing the leadscrew; misalignment can strip threads in the coupler.

---

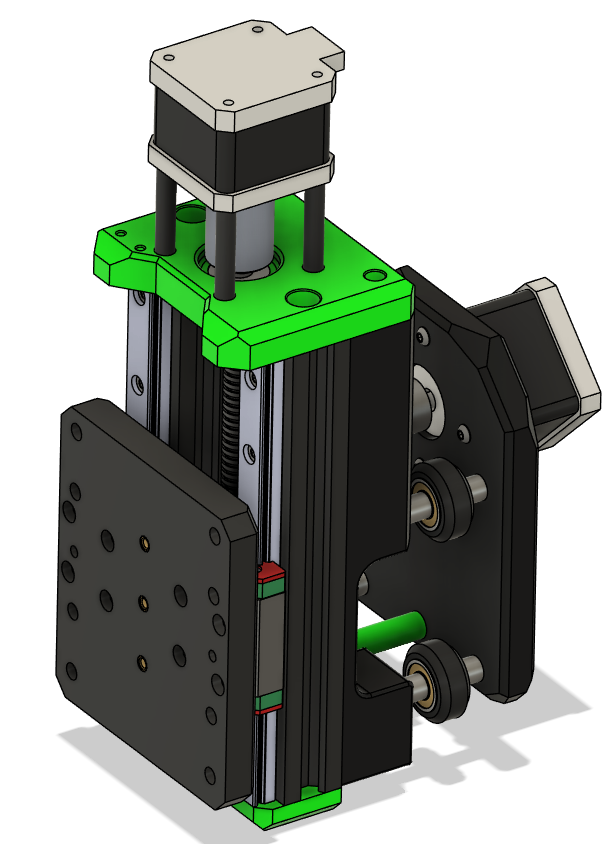
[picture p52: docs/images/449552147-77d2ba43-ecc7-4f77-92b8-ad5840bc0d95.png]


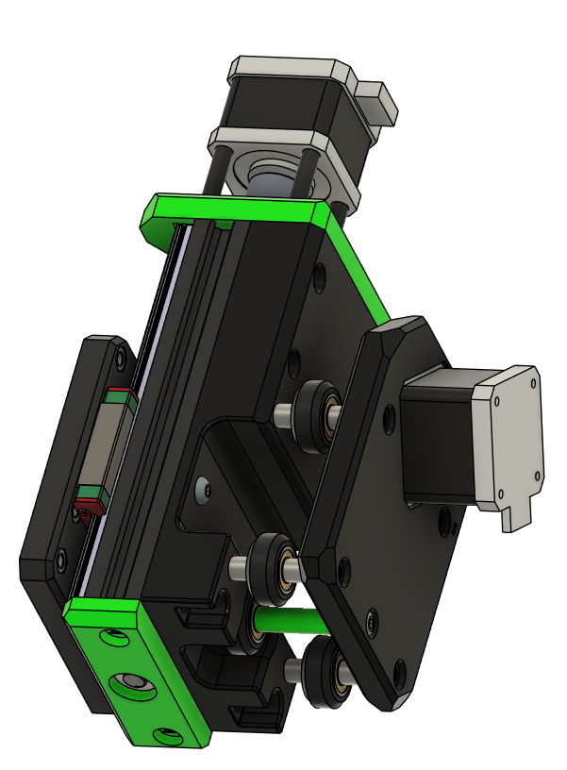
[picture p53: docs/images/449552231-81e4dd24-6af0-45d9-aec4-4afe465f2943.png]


!!! tip
    Ender3 aluminum spacers are 8.35mm. If using 8mm spacers from another source, use the **printed lower middle spacer** to maintain alignment.

---
    
## Ready to Proceed?

After completing these steps, your ready for **Gantry Assembly**.

<p align="center">
  <a href="/EnderCNC/gantry_ends" class="md-button md-button--primary">
    Continue to Gantry Assembly →
  </a>
</p>

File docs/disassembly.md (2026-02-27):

#  Disassemble your old Ender 3

It may seem obvious but in order to build the frame the old Ender must be disassembled.

The parts tray organizer is usefull for keeping all the parts from running away while you are working on the build.

You will thank yourself later for having a clean and organized work area (I wish I could live up to this!)

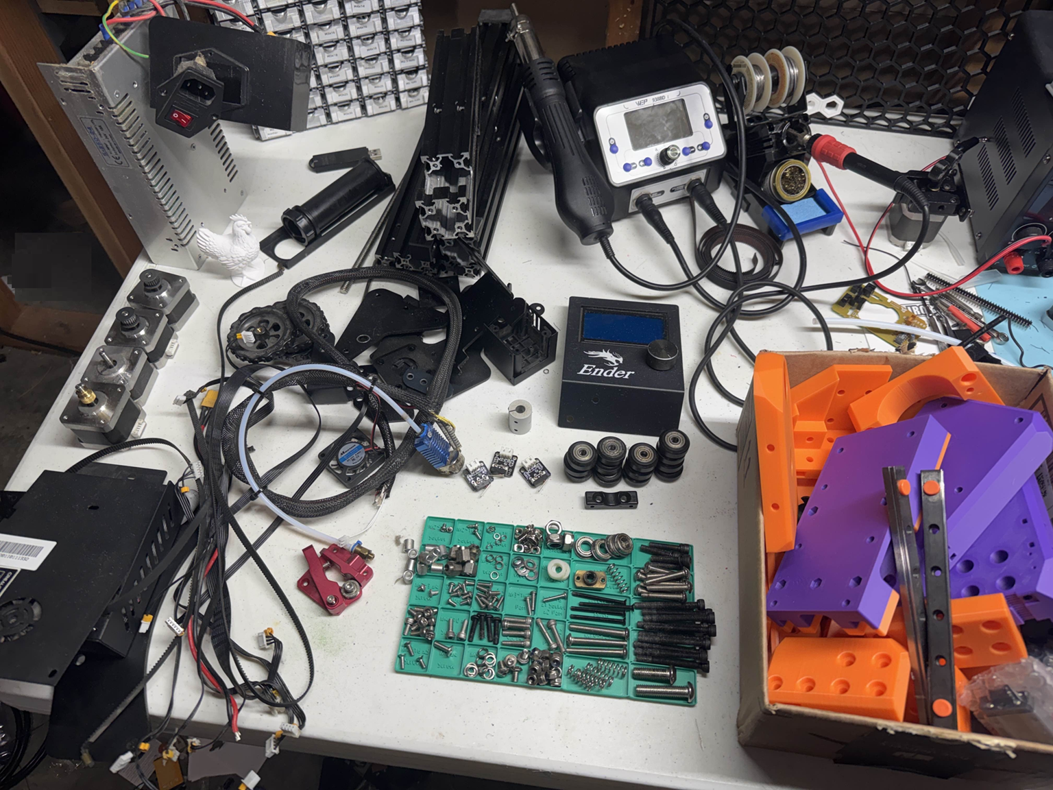
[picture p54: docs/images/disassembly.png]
Disassembly


---

## Ready to Proceed?

After completing these steps, you are ready to start on the **Carriage Assembly**.

<p align="center">
  <a href="/EnderCNC/carriage_prep" class="md-button md-button--primary">
    Continue to Carriage Assembly →
  </a>
</p>

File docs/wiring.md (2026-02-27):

# Wiring and Electronics

This chapter covers connecting limit switches, wiring the motors, and PSU setup.

---

## 1. Parts Required

| Qty | Item | Source | Notes |
|-----|---|---|---|
| 4pc | Limit Switches  | Buy | Endstops for X/Y/Z |
| Wires | As needed | Buy | JST connectors optional |
| 1pc | Electronics Enclosure | Buy/Print | Fits Raspberry Pi / SKR board / SSR |
| PSU | Power Supply | Buy | Ensure safe handling |

---

## 2. Limit Switch Installation

1. Solder wires to all 4 limit switches.  
2. Insert switches into the press-fit slots in the frame.  
3. Test that switches sit securely:
   - If too tight → lightly sand faces.  
   - If too loose → add shims or a small amount of hot glue.  
4. Leave switches **unpressed** until the frame and carriage are fully installed.

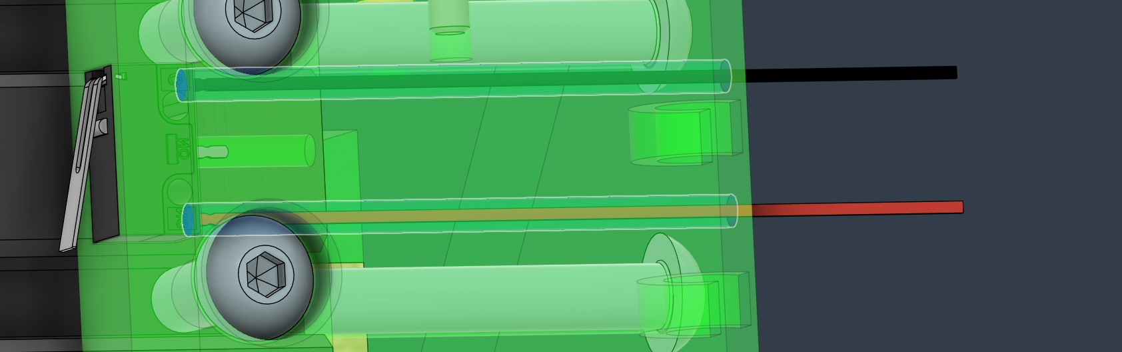
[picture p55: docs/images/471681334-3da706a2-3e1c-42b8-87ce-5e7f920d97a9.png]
Limit Switch Wiring


---

## 3. Wire Management

1. Use zip-tie mounts for clean wire routing.  
2. Keep wires away from moving parts.  
3. Route motor, limit switch, and spindle wires neatly to the electronics enclosure.

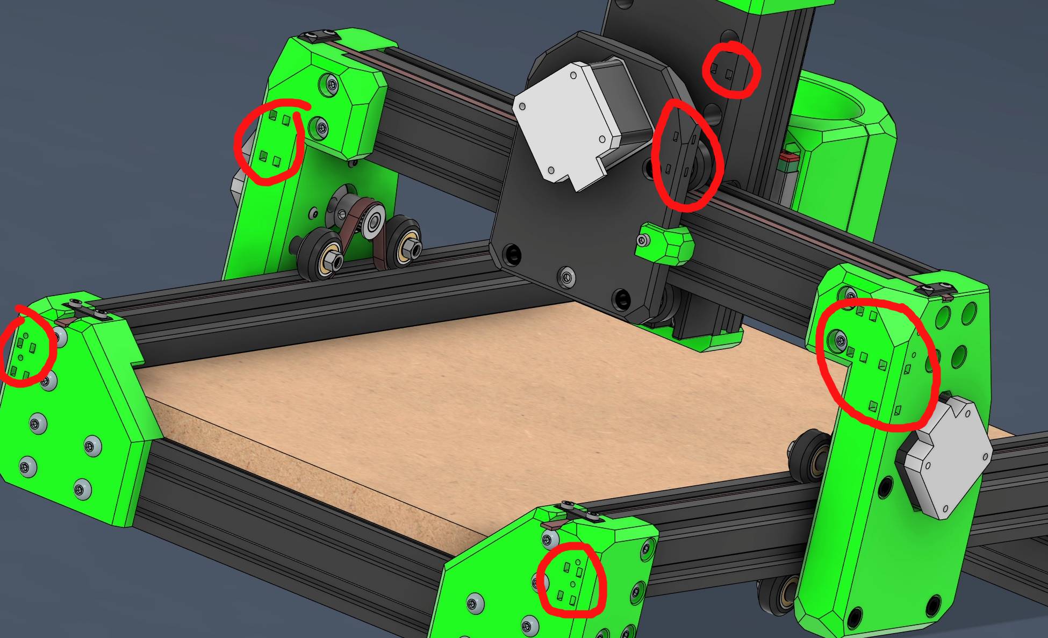
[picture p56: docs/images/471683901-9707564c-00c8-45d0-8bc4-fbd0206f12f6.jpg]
Zip-Tie Mounts


---

## 4. Electronics Enclosure

1. Choose enclosure based on your board (Raspberry Pi, SKR Pico, 4.2.2, 4.2.7).  
2. Modify enclosure if necessary to fit additional components like SSR.  
3. PSU installation:
   - Only connect once wiring is fully complete.  
   - Practice safety and follow electrical guidelines.

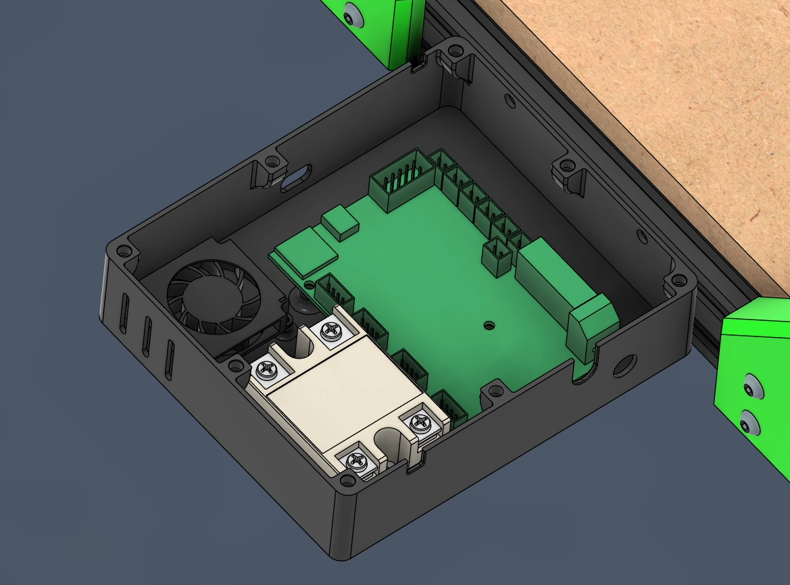
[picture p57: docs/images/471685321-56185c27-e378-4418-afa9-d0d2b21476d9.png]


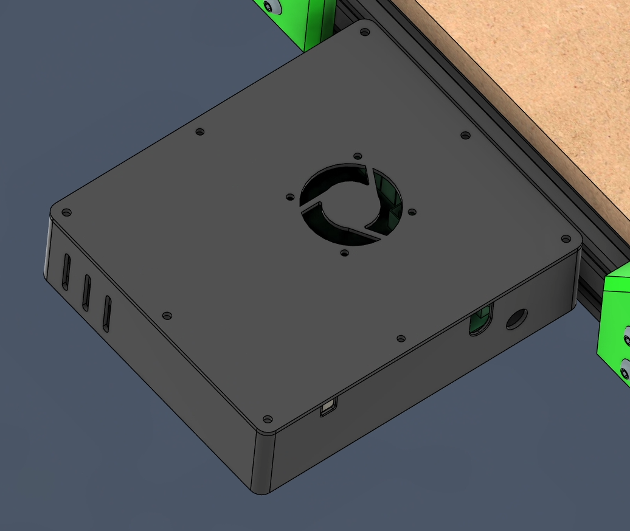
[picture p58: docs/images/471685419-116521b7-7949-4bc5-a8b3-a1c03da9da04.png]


---

### Warnings

!!! warning
    Do not power the machine before completing wiring and verifying all connections.

!!! tip
    Use an old laptop running Klipper as an alternative to a Raspberry Pi if needed.

---

## Ready to Proceed?

You have now completed the wiring and ready to move on to the **Firmware Setup**.

<p align="center">
  <a href="/EnderCNC/firmware" class="md-button md-button--primary">
    Continue to Firmware →
  </a>
</p>

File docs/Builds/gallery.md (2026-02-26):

# Builds from Other Users

**Have you built one? Want to add yours to the list?**

Post a picture or video in the Discord channel #serial-request or DM **Ravenkeeper** on Printables to get a serial!

<style>
.build-gallery {
  display: grid;
  grid-template-columns: repeat(auto-fill, minmax(200px, 1fr));
  gap: 1rem;
  margin-top: 1rem;
}
.build-card {
  border: 1px solid #ccc;
  border-radius: 8px;
  padding: 0.5rem;
  text-align: center;
  background-color: var(--md-default-bg-color);
  box-shadow: 0 2px 5px rgba(0,0,0,0.1);
}
.build-card img {
  width: 100%;
  height: auto;
  border-radius: 4px;
  margin-bottom: 0.5rem;
}
.serial-badge {
  display: inline-block;
  background: var(--md-primary-fg-color);
  color: var(--md-primary-bg-color);
  font-size: 0.7rem;
  font-weight: 700;
  padding: 0.2rem 0.5rem;
  border-radius: 999px;
  margin-bottom: 0.3rem;
}
.picture-needed {
  opacity: 0.6;
  font-style: italic;
  font-size: 0.9rem;
  margin-top: 0.5rem;
}
</style>

<div class="build-gallery">

<div class="build-card">
  <span class="serial-badge">E3CNC.01</span>
  <h4>Steve   <em>Beta Tester</em></h4>
    <a href="../images/447669054-40f72e95-ce02-4052-ad38-b4742addb2c4.jpg" target="_blank">
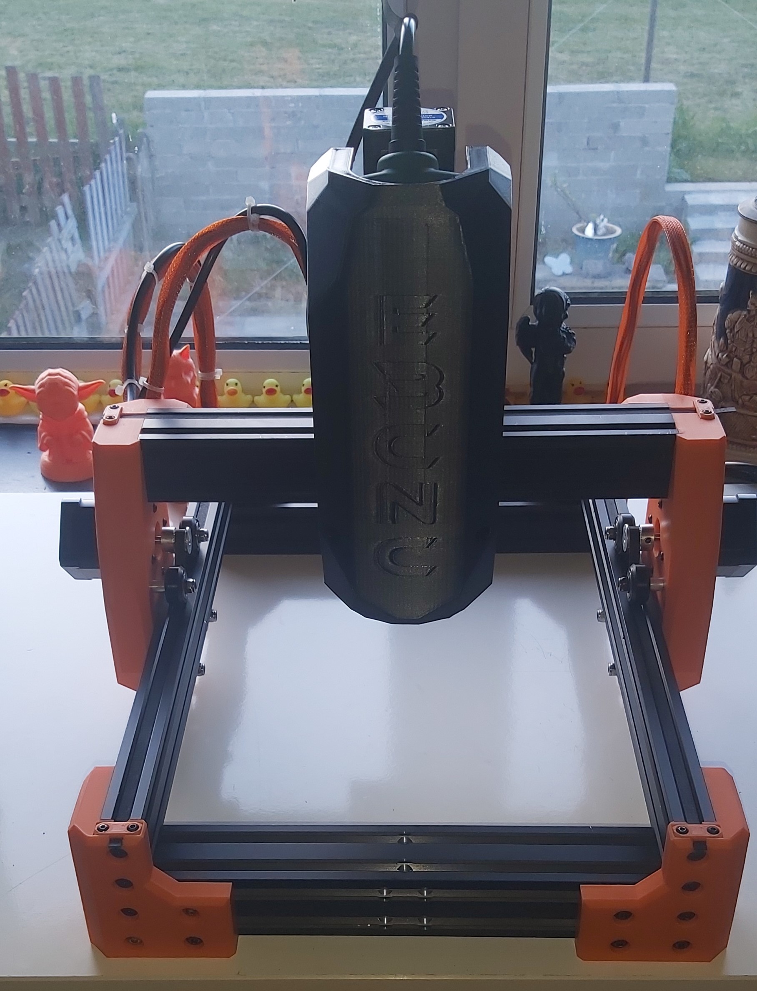
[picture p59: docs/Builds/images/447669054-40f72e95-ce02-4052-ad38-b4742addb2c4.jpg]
Steve's Build
    
  </a>
</div>

<div class="build-card">
  <span class="serial-badge">E3CNC.02</span>
  <h4>Shadowphyre</h4>
    <a href="../images/467523001-18dd2250-4304-4a53-8ac0-229c10cfc96b.jpg" target="_blank">
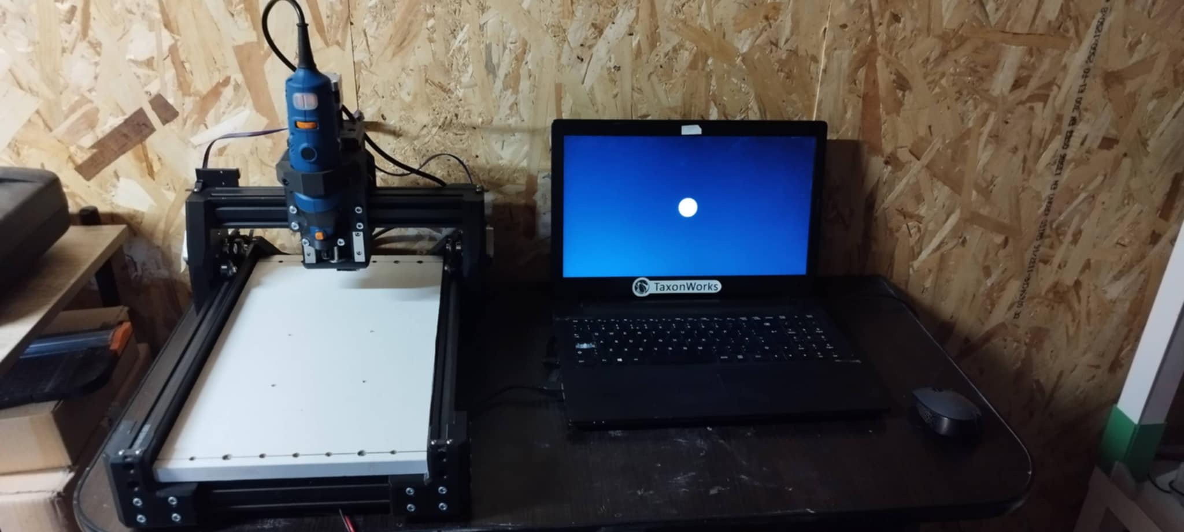
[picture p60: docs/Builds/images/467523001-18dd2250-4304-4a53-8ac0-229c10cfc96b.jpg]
Shadowphyre Build
    
  </a>
</div>

<div class="build-card">
  <span class="serial-badge">E3CNC.03</span>
  <h4>scalaw4g</h4>
    <a href="../images/473723616-a17f3feb-f31b-4c5d-b64b-5b7f2bb7a775.jpg" target="_blank">
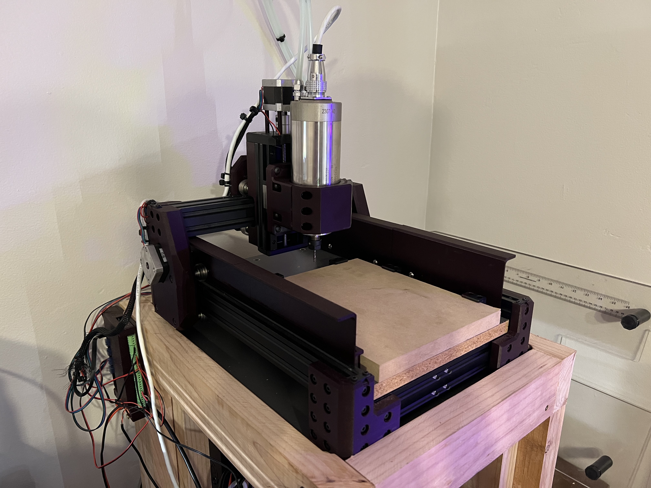
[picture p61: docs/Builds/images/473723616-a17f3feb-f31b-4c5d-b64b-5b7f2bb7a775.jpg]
scalaw4g Build
    
  </a>
</div>

<div class="build-card">
  <span class="serial-badge">E3CNC.04</span>
  <h4>LostPhysicist</h4>
  <a href="../images/502998145-15411b45-23be-40e2-a9ff-7dc25a7b23b3.jpg" target="_blank">
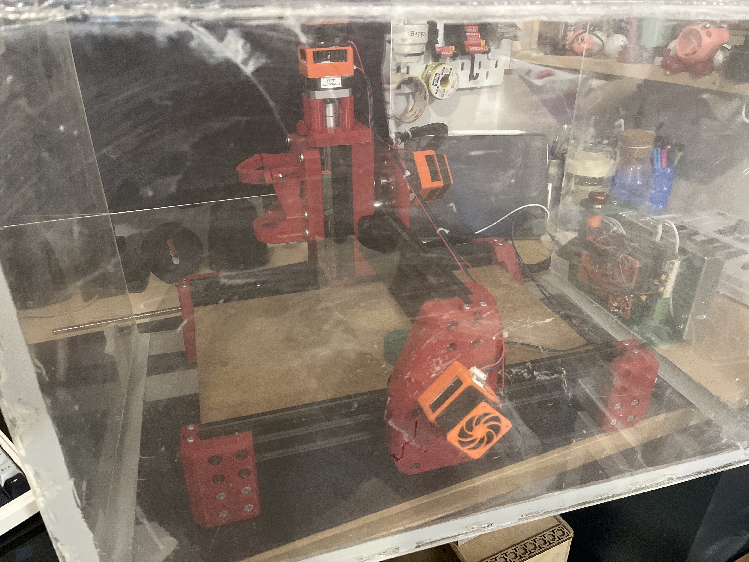
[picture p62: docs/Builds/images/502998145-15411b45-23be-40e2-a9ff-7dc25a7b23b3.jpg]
LostPhysicist Build
    
  </a>
</div>

<div class="build-card">
  <span class="serial-badge">E3CNC.05</span>
  <h4>Spoonie</h4>
  <a href="../images/502998210-c12e0b00-3522-447a-aa38-5451ce4f32af.png" target="_blank">
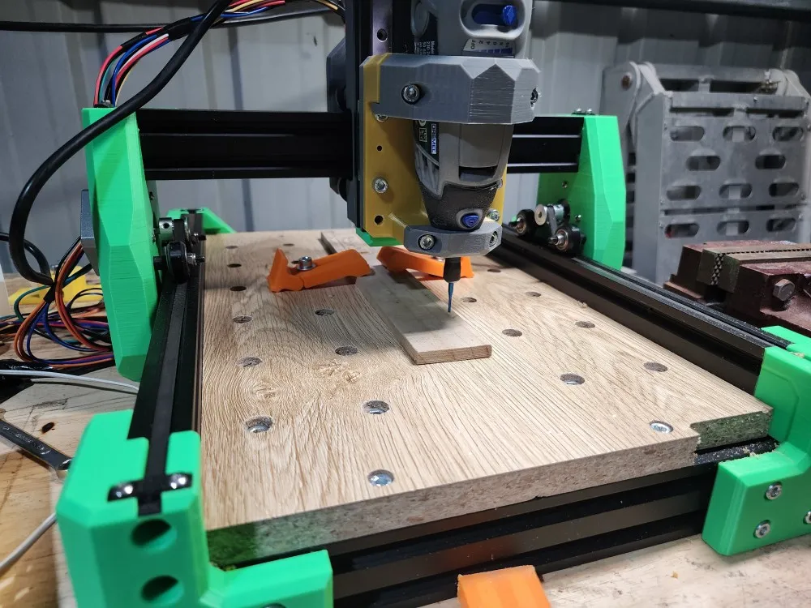
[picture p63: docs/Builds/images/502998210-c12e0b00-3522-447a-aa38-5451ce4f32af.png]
Spoonie Build
    
  </a>
</div>

<div class="build-card">
  <span class="serial-badge">E3CNC.06</span>
  <h4>tim_loi</h4>
  <a href="../images/502998294-a2c76cf8-d2f3-4067-b3a0-3baab1395d1e.png" target="_blank">
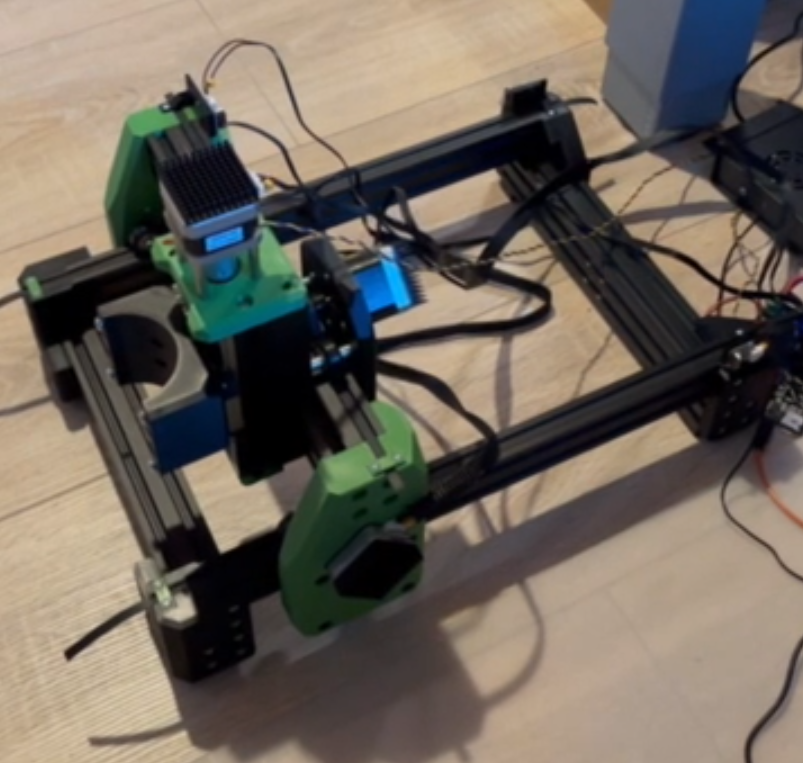
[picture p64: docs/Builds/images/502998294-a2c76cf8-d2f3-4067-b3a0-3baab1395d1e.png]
tim_loi Build
    
  </a>
</div>

<div class="build-card">
  <span class="serial-badge">E3CNC.07</span>
  <h4>slyngSh0t</h4>
  <a href="../images/502998370-af3ce84c-d52e-4787-8671-ce4d9b47047c.png" target="_blank">
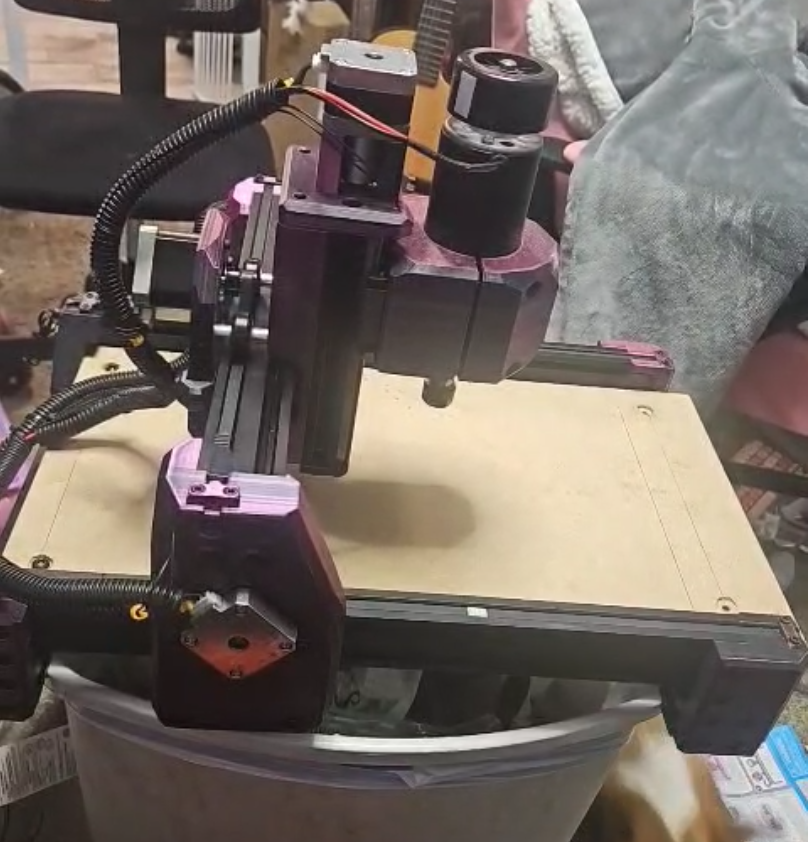
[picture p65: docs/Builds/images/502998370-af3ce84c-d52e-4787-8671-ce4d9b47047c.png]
slyngSh0t Build
    
  </a>
</div>

<div class="build-card">
  <span class="serial-badge">E3CNC.08</span>
  <h4>piro_o</h4>
  <a href="../images/524280168-ac9c7333-6052-47d7-ad32-e748e272c603.jpg" target="_blank">
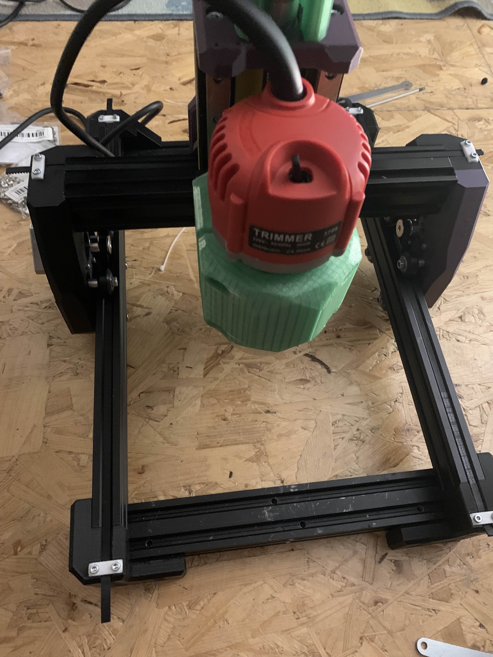
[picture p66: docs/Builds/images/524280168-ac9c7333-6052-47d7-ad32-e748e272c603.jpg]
piro_o Build
    
  </a>
</div>

<div class="build-card">
  <span class="serial-badge">E3CNC.09</span>
  <h4>__vz__</h4>
  <div class="picture-needed">Picture needed</div>
</div>

<div class="build-card">
  <span class="serial-badge">E3CNC.10</span>
  <h4>Pickle</h4>
  <a href="../images/524281350-a76dad47-9462-424f-a48d-ffa021440296.jpg" target="_blank">
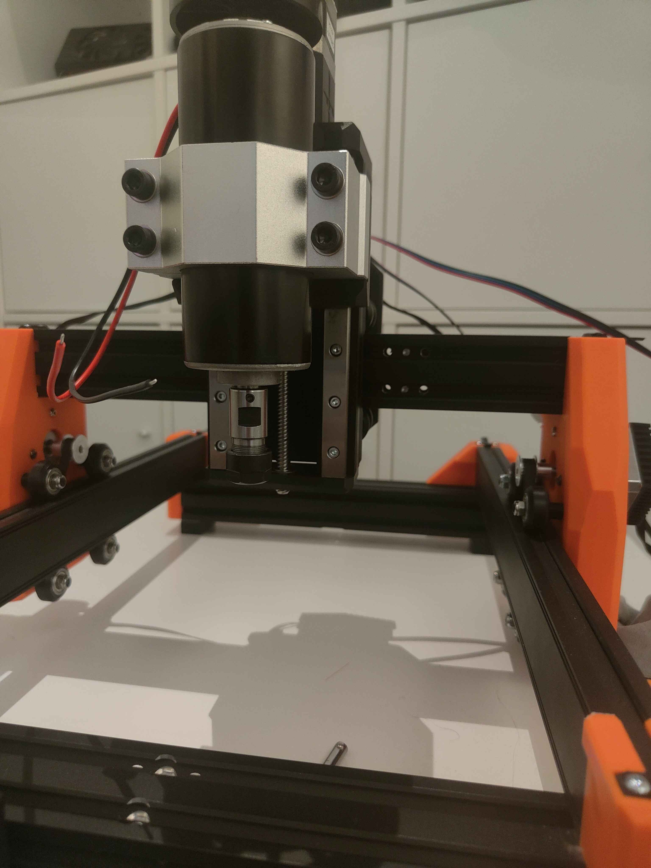
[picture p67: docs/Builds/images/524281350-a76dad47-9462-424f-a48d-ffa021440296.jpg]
Pickle Build
    
  </a>
</div>

<div class="build-card">
  <span class="serial-badge">E3CNC.11</span>
  <h4>Rian_ODonnell1337</h4>
  <a href="../images/524281804-f5c53411-1e5f-4740-853d-6984495dee02.jpg" target="_blank">
    Rian_ODonnell1337 Build
  </a>
</div>

<div class="build-card">
  <span class="serial-badge">E3CNC.12</span>
  <h4>Nulterm</h4>
  <div class="picture-needed">Picture needed</div>
</div>

<div class="build-card">
  <span class="serial-badge">E3CNC.13</span>
  <h4>Laika</h4>
  <a href="../images/524283090-b1b6a432-680c-4392-b465-8f572732ee6b.jpg" target="_blank">
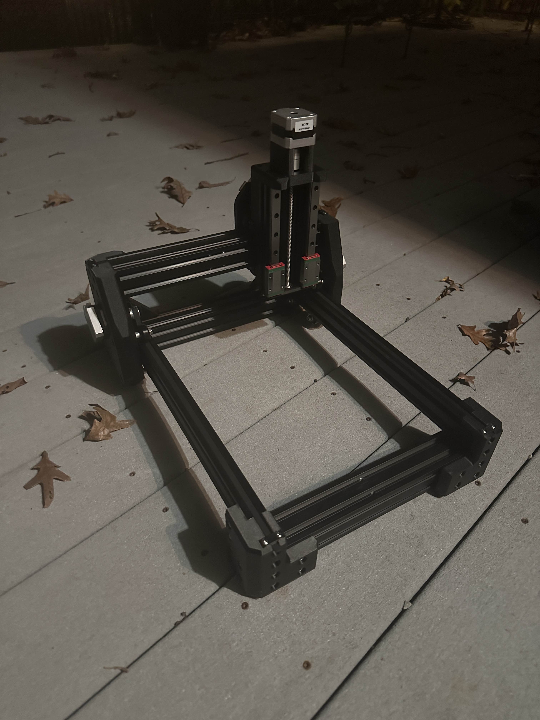
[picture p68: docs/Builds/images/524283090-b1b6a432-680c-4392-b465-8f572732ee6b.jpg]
Laika Build
    
  </a>
</div>

<div class="build-card">
  <span class="serial-badge">E3CNC.14</span>
  <h4>VEK</h4>
  <a href="../images/524283505-433246ef-ba87-4ff9-9061-19262ef5be22.png" target="_blank">
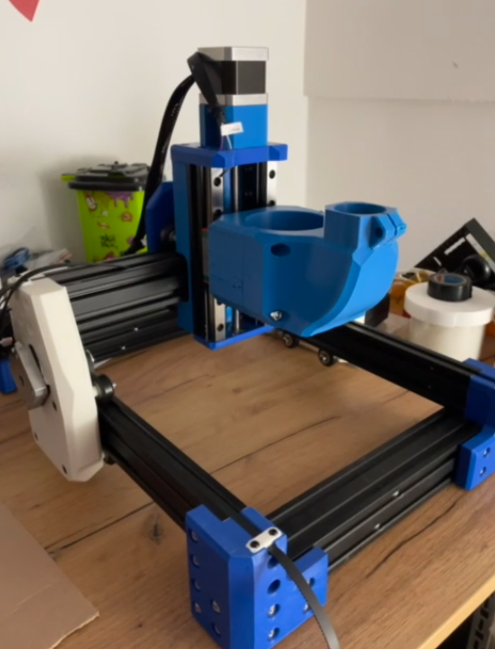
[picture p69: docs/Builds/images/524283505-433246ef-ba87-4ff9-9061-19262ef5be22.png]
VEK Build
    
  </a>
</div>

<div class="build-card">
  <span class="serial-badge">E3CNC.15</span>
  <h4>superjasiek</h4>
  <a href="../images/524284587-909b0d43-5cea-43f3-81fa-6d1a7bf38a4c.png" target="_blank">
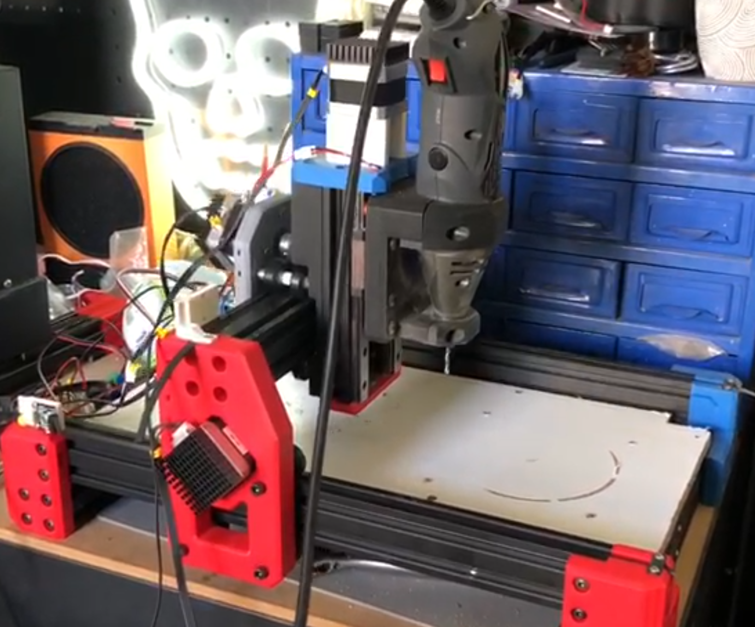
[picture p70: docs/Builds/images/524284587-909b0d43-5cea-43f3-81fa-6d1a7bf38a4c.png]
superjasiek Build
    
  </a>
</div>

<div class="build-card">
  <span class="serial-badge">E3CNC.16</span>
  <h4>itsmosby</h4>
  <a href="../images/524285033-0e28263a-54ac-4ce4-a752-f5e4068d18bd.jpg" target="_blank">
    itsmosby Build
  </a>
</div>

<div class="build-card">
  <span class="serial-badge">E3CNC.17</span>
  <h4>TimToBeat</h4>
  <a href="../images/529392693-df2071ae-4e44-489c-87f6-6c19672b9223.jpg" target="_blank">
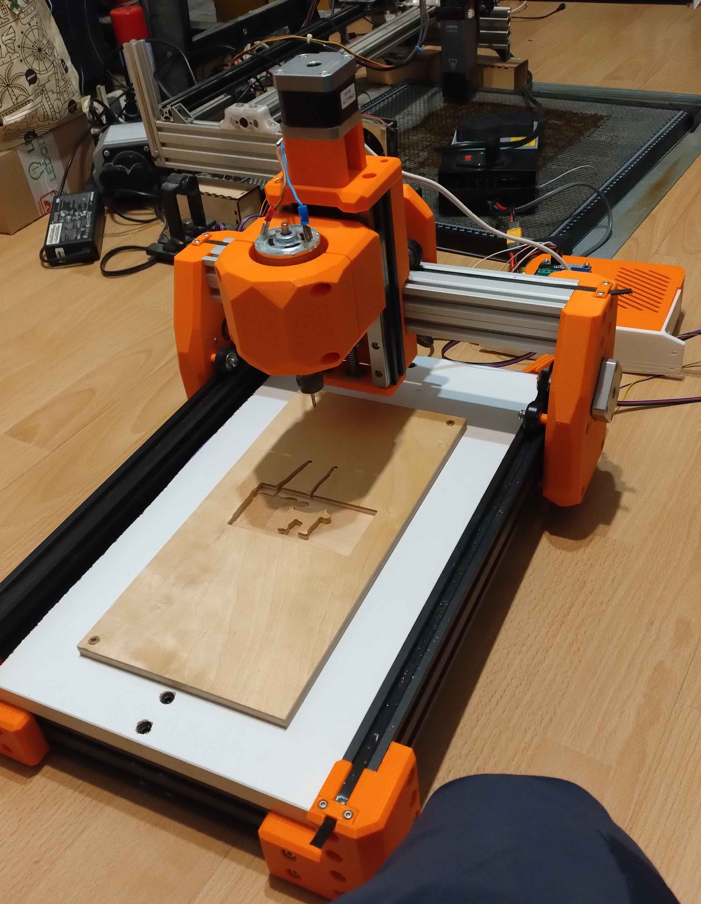
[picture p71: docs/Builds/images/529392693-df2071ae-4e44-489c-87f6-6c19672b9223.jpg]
TimToBeat Build
    
  </a>
</div>

<div class="build-card">
  <span class="serial-badge">E3CNC.18</span>
  <h4>Kestranor</h4>
  <a href="../images/530238931-c31b80af-27df-4b9a-9371-5a7a85ac506e.png" target="_blank">
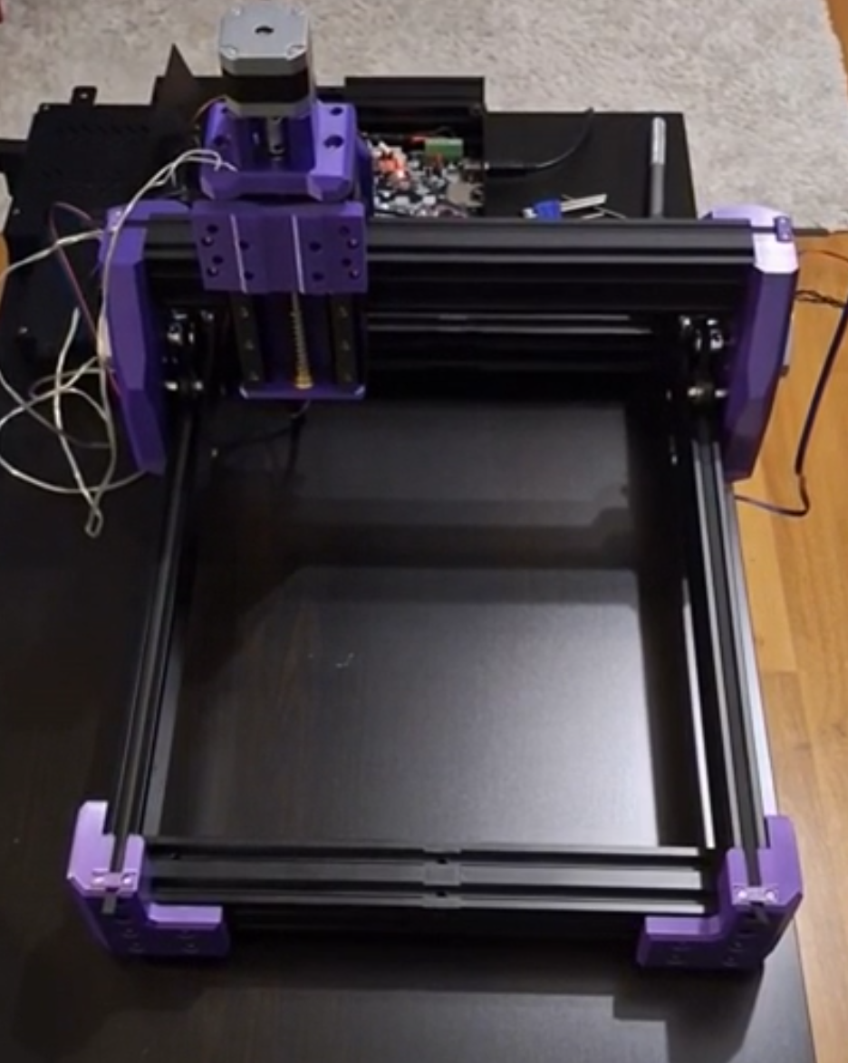
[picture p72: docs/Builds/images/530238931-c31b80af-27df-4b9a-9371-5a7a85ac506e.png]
Kestranor Build
    
  </a>
</div>

<div class="build-card">
  <span class="serial-badge">E3CNC.19</span>
  <h4>Dillpickckle</h4>
  <a href="../images/530239184-270eda31-7724-4a57-b8a9-f81a26e8c230.png" target="_blank">
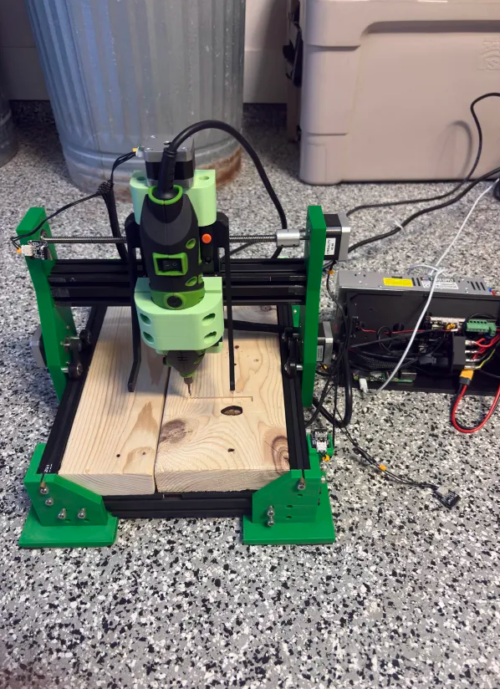
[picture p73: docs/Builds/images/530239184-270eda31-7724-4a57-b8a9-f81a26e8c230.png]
Dillpickckle Build
    
  </a>
</div>

<div class="build-card">
  <span class="serial-badge">E3CNC.20</span>
  <h4>Scherwiii | Steven</h4>
  <div class="picture-needed">Picture needed</div>
</div>

<div class="build-card">
  <span class="serial-badge">E3CNC.21</span>
  <h4>blaze</h4>
  <a href="../images/530239375-a522d95f-7237-4cf6-a4d5-c84f2eab05fa.jpg" target="_blank">
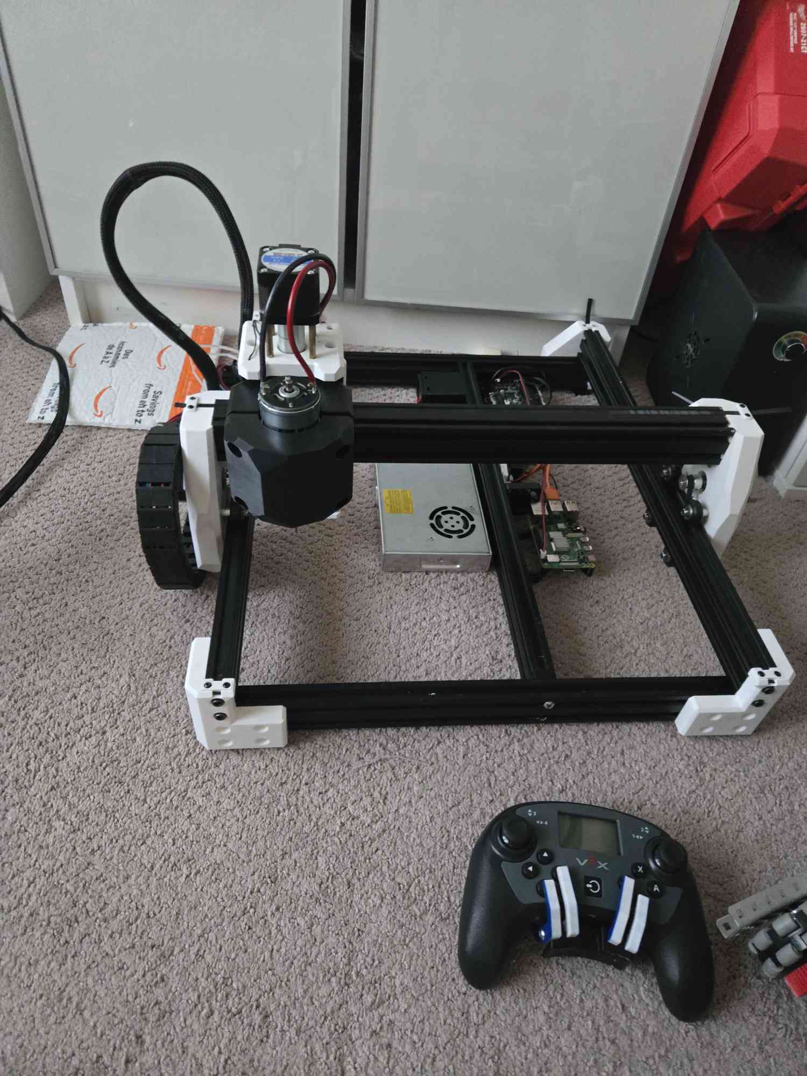
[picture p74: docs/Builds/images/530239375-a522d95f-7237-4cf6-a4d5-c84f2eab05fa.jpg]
blaze Build
    
  </a>
</div>

<div class="build-card">
  <span class="serial-badge">E3CNC.22</span>
  <h4>YAHYALD</h4>
  <a href="../images/IMG_20260118_155550.jpg" target="_blank">
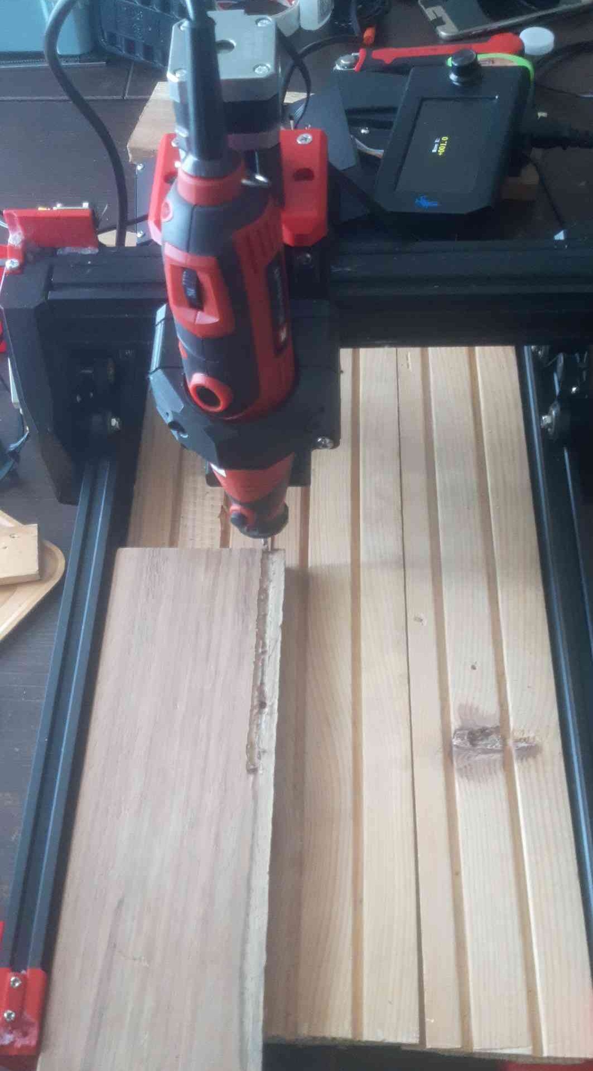
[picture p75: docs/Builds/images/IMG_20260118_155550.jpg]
YAHYALD Build
    
  </a>
</div>

<div class="build-card">
  <span class="serial-badge">E3CNC.23</span>
  <h4>_TOXA_5842</h4>
  <a href="../images/20260206_143920.jpg" target="_blank">
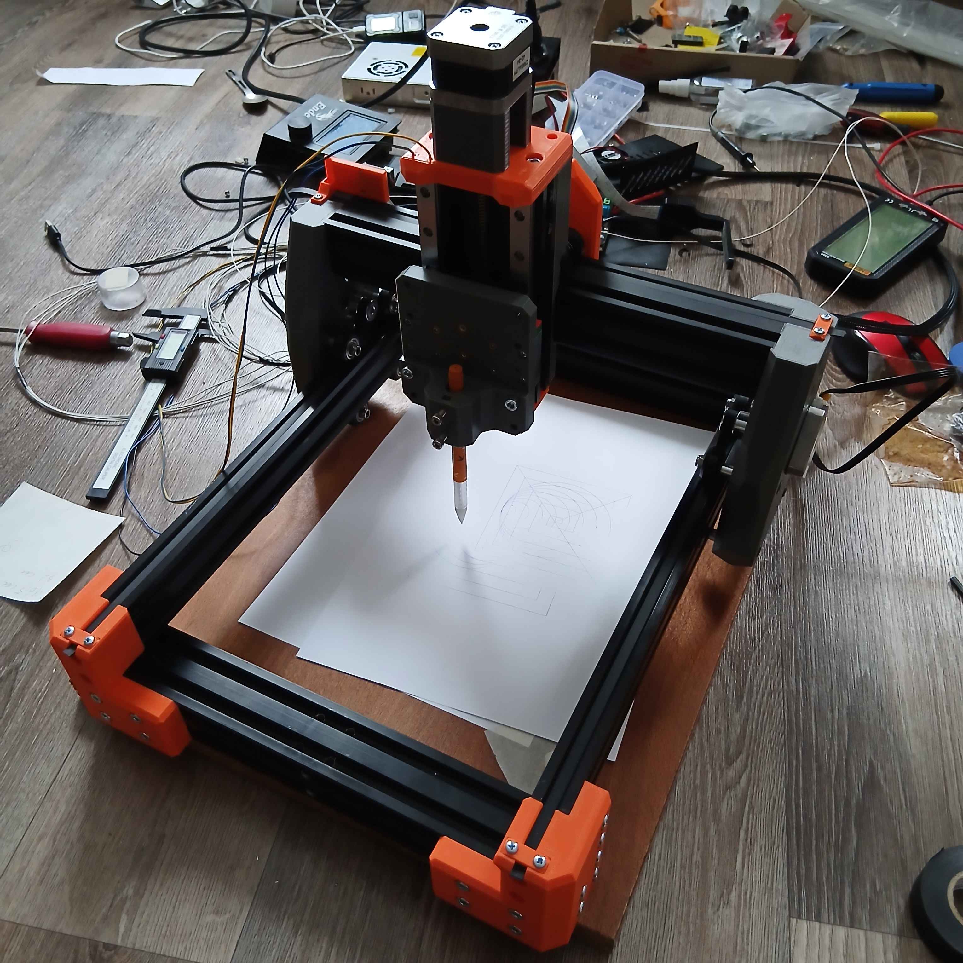
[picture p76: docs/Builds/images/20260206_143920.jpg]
_TOXA_5842 Build
    
  </a>
</div>

</div>

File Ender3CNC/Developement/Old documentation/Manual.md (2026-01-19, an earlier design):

# Ender 3 PRO based CNC Build manual

### !! Note: This "guide" might contain errors with hardware parts, if you find any issue please let me know !!

## Things you'll need. 
- Ender 3 PRO (not the non pro version)
- M5 tap
- Ability to cut Alu extrusions to length.
- Hexdrives
- RaspberryPi or old laptop running linux/klipper. (if you want to use klipper)
- Dremel/Spindle of your choice (You might have to adjust the dremel clamps to fit yours)
- Printed pressfit pulley extraction tool (this can be tricky, but you can also cut them off if you want)

### Print settings I used: PLA+, 5 wall, 5 top, 5 bottom, 40% gyroid.

## Parts print Orientation for no supports needed. 


## Bearing Choice
### If you dont have 608Z use the F688Z from the Ender 3 Pro X axis tensioner. 
bearing_choice

## M3 Heatsets ( M3x5x4 "Voron spec") 

### X-Motor plate


### Corner Brackets
corner_heatsets

### XZ Carriage Plate
XZ_gantry_heatsets

### Dremel Plate
dremel_plate_heatset

### Z Carriage
Z_carriage_heatsets

### XY Joints 
XY_joints_heatsets

## M5 Locknuts - These should be pressfits!

### Z Carriage 
pressfit m5 hexnuts

### XZ Carriage Plate
xz_plate_pressfit m5 hexnuts

## Blind Joints

### should be 20mm offset both front and back. 
  
blind joint back

### What is this part? 
* This is the "X Endstop Buffer". It attaches to the X motor plate on the X endstop side to a heatinset.
* This "buffer" is needed if you are homing with the vacuum attachment or "splashguards" on to not collide in the Y extrusion.
* You will not need this attached if you are not using the vacuum attachment.
* M3x8/10 screw




# The build! 

### DO NOT PRESS IN THE ENDSTOPS AT ANY POINT UNTILL YOU START WIRING! YOU MIGHT NOT GET THEM OUT AGAIN AS THEY ARE PRESSFITS. 

## Frame
| Qty  | Item | Source  | Notes |
|---|---|---|---|
| 48pc | M5x16 BHSC | BUY | |
| 4pc  | M5x40 | Ender3  | |
| 4pc  | M5x8 | Ender3  | |
| 4pc  | M5 1mm Shims | BUY | |
| 52pc | M5 T-nuts | BUY | |

* DO NOT PRESS IN THE ENDSTOPS YET.
* Assemble frame as shown, take note of blind joints and 20mm offset on the back extrusion and check for square.
  - I found it easier to get a square frame on a known flat surface by adding the XY joints after the frame is built. Its a bit tricky, but very doable.

assable_frame

## XY joints
| Qty  | Item | Source | Notes |
|---|---|---|---|
| 8pc  | M5x45 SHSC | Ender3 | Remove the shims from these |
| 8pc  | M3x10 | BUY | |
| 8pc  | 8mm Spacer (Printed or 5mm bore Alu) | BUY | Do not use the aluminum spacers from the Ender3 here  |

* DO NOT PRESS IN THE ENDSTOP YET.
* Loosely attach the 20T pylleys.
* Assemble XY joints as shown WITHOUT the endstop.



## Mount XY joints to the frame. 
| Qty  | Item | Source | Notes |
|---|---|---|---|
| 8pc  | V-Wheels | Ender3 | |
| 8pc  | M5 Locknuts  | Ender3 or BUY  | |

* DO NOT PRESS IN THE ENDSTOP YET.
  - I slid the xy joint on while the frame was built.
  - Put on the 2 bottom wheels and loosely add M5 nut to them.
  - Place the bottom wheels in the V slot, hold it at a slight angle.
  - Add the 2 top wheels to the Vslot and angle up the XY joint with a slight wiggle the top screws should pop in the wheels.
  - Bit tricky but doable. Or if you want to just take of the 2040 from the frame and slide them on. Might need to re-square the frame though.
* After mounting both XY joints, doublecheck the measurement between the X extrusion mounting points before cutting the X extrusion.
* Ender 3 frames might not be 100% the same. so yours might be +- from 300mm.
* After cutting the X extrusion to size you need to tap 4 new m5 threads on the cut side.

x_beam

## Assemble X+Z Carriage
| Qty | Item | Source | Notes |
|---|---|---|---|
| 4pc | M3x8 BHSC | Ender3 | |
| 2pc | M3x10 | BUY | |
| 10pc  | M5x16 BHSC | BUY | |
| 2pc | M5x8 BHSC | Ender3 | |
| 4pc | M3x40 | Ender3 | |
| 4pc | M5x45 SHCH | Ender3 | Remove the shims |
| 1pc | M5x65 BHSC | BUY | |
| 12pc  | M3x8 SHSC | BUY | |
| 2pc | M3x16 BHSC | Ender3 | |
| 9pc | Alu Spacers | Ender3 | |
| 1pc | 28.35mm Printed Spacer  | Printed  | |
| 5pc | V-wheels | Ender3 | |
| 4pc | 32.60 mm spacer | Printed  | |
| 8pc | M3x10 BHSC | Ender3 | |

* DO NOT PRESS IN THE ENDSTOP YET.
* Cut Ender3 2020 extrusions to 150mm x2 pieces.
* Tap m5 threads in both ends of the 150mm 2020 extrusions.
* Press in bearings if you didnt already.
* Loosely attach the coupler to the Z motor.
* Loosely attach the 20T pulley to the X motor. 
* Attach both Z and X motors to their plates before continuing.
* Attach the 2020 extrusions as square and paralell as you can.
* Mount the X motor carriage to the ZX carriage with the wheels and spacers.
  - This can be a bit tricky, but doable after picking up the wheels and spacers from the floor a few times, sorry.
  - NOTE! Alu spacers from the Ender 3 are 8.35mm long, if you use 8mm long spacers from another source please use this [add part link here] printed spacer part for the lower middle wheel.
* Attach the Z bottom bearing plate and Z motor plate.
* Attach the MGN12 rails with the MGN12H carriages to the 2020 extrusions. (use a printed MGN12->2020 tool to get good alignment on the rails. Printables, Thingiverse etc)
  - NOTE! If you cut the 2020 a bit shorter than 150mm or the rails you ordered/cut are over 150mm dont worry, in the Z motor plate there are cutouts for the MGN rails to slide into if they are too long (max 4mm clearance)
* Attach the Z leadscrew nut to the Z carriage.
* Mount the Z carriage to the MGN12H carriages. - After mounting the Z carrige to the rails, slide it up and down to check for any binding in the rails, adjust rails if needed.
* Cut leadscrew to size. ~180mm but doublecheck with your setup. it should just about poke out of the lower Z bearing.  
* Screw in the leadscrew from the bottom bearing all the way to the Z motor coupler and secure it.
* Slide the assembly on the X extrusion that was cut to size. 






## Attach the X+Z assembly to the XY joint.
| Qty  | Item | Source  | Notes |
|---|---|---|---|
| 8pc  | M5x30 BHSC | Ender3  | |
| 4pc  | M5x16 BHSC | BUY | |



## Run the belts
| Qty  | Item | Source  | Notes |
|---|---|---|---|
| 3pc  | ~500mm GT2 6mm Belt | BUY | Control measure before cutting to length!! |
| 12pc | M3x10 | BUY | Migth be some spares from the Ender3 |
| 6pc  | Printed Belt Clamp | Printed | |



## Attach the Dremel clamp or Ø52-65mm clamp depening on what you use. 




# Wires

### Now you can finally touch the limit switches. 

- Solder wires to 4x limit switches as you do for any 3d printer. If you are using wires with JST on the end, slide the wires into the wire holes for the endstop and then solders them to the limit switch.
- With the wires soldered on guide the limit switch into the hole and press it in, make sure it sits secure.
- If its too tight, lightly sand the faces of the limit switch and try again untill it fits.
- if its too loose use something to shim it tight or add a bit of hotglue to the hole then push the switch in. 


## Ziptie mounts for wire pathing. 


## Electronics enclosure. 
- If you are using a 4.2.2/7 board or a SKR Pico there are housings for those with room for SSR on Printables. 
- You'll have to edit the part to fit a RPI if you use one. ( I use a old laptop running Ubuntu and klippers as a RPI)
- Any other enclosure/board setup you'll have to make something that fits your needs. 



### PSU: You are on your own here for liability reasons, practice good safety.

## Machine should now be built and if everything feels smooth when moving it by hand you are good to start on firmware!

### Reference printer.cfg for klipper here. 

- For Klipper set everything up as you do with any 3D printer running klipper. Read the Klipper docs if you dont know how to.
- For GRBL base do the same according to your setup. 

# Fusion360 Klipperized Post Processor [here!](https://github.com/Futtawuh/EnderCNCs/blob/main/Ender3CNC/fusion360%20post%20processor.md)

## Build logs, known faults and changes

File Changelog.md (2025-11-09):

# 09.11.25
- Added new version of the front corners to printables. [Not uploaded to the CAD file yet] The older ones could make it hard to get the spoilboard in place.  If you want the old ones they are available in the CAD file. 

# 29.07.25

- Cleaned up CAD a bit, new CAD uploaded today that is ONLY for the cheap version that is tested and works. There will not be more updates to this CAD version unless issues arrise.
- New CAD with mods/upgrades will be coming soon. MGN rails etc. More info? join the Discord.

# 28.07.25

- Added new CAD version, no major changes yet, only updates to the BEEFY dremel clams, Ø52-65mm spindle clamps. 
- Removed old dremel clamp and old Z carriage from STL's. [still available in CAD]
- Added BEEFY version of the dremel clamp.
- Added .step for BEEFY clamp only if you dont want the full CAD to adjust it. [printables]
- Added new Z carriage for the BEEFY clamps [does not fit with the old dremel clamp]
- Removed faceplate from Printables, does not fit the new BEEFY clamps [Will come back soon]
- As always, there is no way for me to test the clamps on every “clone” of a dremel. You'll have to print a test and adjust as needed.
- Added splash_guard to printables. Limits dust to the belt paths. [ only works if the spoilboard is under 24mm thick]
- Full credit to Shadowphyre for the new BEEFY dremel clamps. 

# 24.07.25
- Back after vacation !
- Added new electronics enclosure models, 15mm more clearance for wires. 
- Added new version of Z motor spacers, old ones could bend under warmer weather. There is a clean version, one with logo single color and one dual color logo version. Choose one and print 2 pieces. [Printables]
- Added new version of Z_top_bearing mounts for the new Z motor spacers. ( You do not have to reprint these if you want use the new Z motor spacers, only removed holes for the old spacers, should not be visible either way) [Printables]
- Added support for the Ender 3 NON-PRO using the 2040 from under the bed and not 4040 like the E3PRO. (will be uploaded soon with the new CAD version)

# 15.07.25

- Added STL's to the Printables page. 
- Ø65mm clamp added [untested, will be tested shortly] Should not remove any cutting area according to CAD.
- 4.2.2/SKR Pico+SSR enclosure added (will add mount for the underside of the machine later)
- 20mm “mod” front corners merged to main build. Old corners are still in CAD but has 20mm less cutting area on Y axis. 

# 29.06.2025
- Basic BOM listed. Please note that i might have not counted correclty. If you find any issues please let me know. BOM [here](https://github.com/Futtawuh/EnderCNCs/blob/main/Ender3CNC/BOM.md)
- Added optional front corners, adding 20mm extra Y cutting area. No changes to BOM.
- These are not added to the main CAD yet. But you can find them [here](https://github.com/Futtawuh/EnderCNCs/tree/main/Ender3CNC/Mods)
- Thanks Shadowphyre for the suggestion!

# 18.06.2025
- Macros for XYZ-0 positioning uploaded. 
- Tested out vac attachment, seems to do its job on wood, will test more on different materials. 

# 14.06.2025
- Had to wait for a new dremel as my new one was DOA. It arrived today, furter testing and cutting videos will be uploaded shortly!
- Will be testing differnt kinds of wood, some types of Plexi/acrylic and ofcourse some unknow grade aluminium. 

# 04.06.2025

### Ender3pro-CNC CAD uploaded!
- Fully built by me and a "beta" tester. Everything should fit nicely and easy enough to assemble!
- Build guide still not 100% finished, but it should give most pointers that you need
- Build guide and CAD is found ["HERE!"](https://github.com/Futtawuh/EnderCNCs/tree/main/Ender3CNC)
- If you need .step contact me on Discord: ravenkeeper (filesize too big to upload)

# 05.05.2025

### There will be multiple versions as time goes on. 
- Facelift version of the EnderCNC is in "release" stage, CAD wont be updated unless issues arise during use. 
- New Ender3CNC version soon in "BETA". Base 99% on the Ender 3 PRO. Cheaper alternative on vwheels etc.

Picture of the new version.


# 28.04.25

Facelift version built, will do minor tweaking to CAD, but everything fits like it should. New CAD will be uploaded soon.

# 26.03.25

* Uploaded facelift version CAD. This version is tested OK, does alu with a dremel pretty nicely if you know how to tune your DOC, feeds and speeds. 



# 20.03.25

* Udated CAD file. Added new look to the XY joints as the original was kinda lacking in the looks department. Added both dual bearing and single bearing version. (if you want the original one they are also in the CAD) 
 

* Relocated the X endstop to be in-set into the LEFT XY joint.
- (Wires coming out on the other side where the wire loom connects to the XY joint)
 

* Comparison old vs new.
 

# 19.03.25

* Added belt tension system for the Y belts on the Y motor carriages.
 

* Added "splash-guards" to limit debris from spilling over to the Y axis belts and rods. ( need to cut them in half in slicer unless you have a 400mm printer )
 
 

* Maktia 700 series ( or other Ø65mm spindle ) clamp added.
 

* Remixed Z carriage for more Z travel. But you'll have to cut the teethed part off a 8mmID 20t pulley, or use another 8mmID locking nut on the Z leadscrew. (lower 20t pulley cut to size on picture below)



* Bigger holes for ziptie cable management.
* Several fixes to the XY joints:
  - Fixed so the X carriage cant home over the Y extrusion.
  - Shorter screws for the Y belt clamps.
  - Longer XY joints with 55mm + 29mm LM bearings for more stability (optional)
  - You can now use either LMK10LUU or LMK10LUU + LM10UU for the XY joints. Using LMK+LMU does not reduce cutting area.

# 02.01.25

* Added 8mm rod mod CAD, using 8mm rods and 2x LMU8 bearings on each side for stiffness. (45mm long x2)

# 22.12.24

* Updated CAD with most of the hardware. Still a little bit left.
* Updated CAD X travel/limit switch for Z to not crash into Y extrusion if X homing without Z homed first. 

# 21.12.24

* Create Github
* Added CAD files
* Added DXF / PDF file of x gantry back plate.

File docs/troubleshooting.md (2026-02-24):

# Troubleshooting

Common issues and fixes during your Ender 3 PRO CNC build.

---

## 1. Frame Issues

- **Frame not square:** Adjust diagonal measurements.  
- **XY joints binding:** Loosen wheels slightly and re-align.  

---

## 2. Carriage & Z-axis Issues

- **Z carriage binds:** Check MGN12H rail alignment.  
- **Leadscrew doesn’t turn smoothly:** Verify coupler alignment and thread engagement.

---

## 3. Belts & Spindle

- **Belts slipping:** Retighten or replace clamps.  
- **Spindle not secure:** Adjust printed clamp or use alternative spacer.

---

## 4. Wiring & Electronics

- **Limit switch not triggered:** Check wiring and press-fit alignment.  
- **Motors not moving:** Verify connections and firmware configuration.

---

### Tips

!!! tip
    Test movement manually before applying power or running G-Code.

!!! warning
    Always disconnect PSU before making wiring adjustments.

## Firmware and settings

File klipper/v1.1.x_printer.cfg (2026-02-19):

######################################################################
# E3CNC
######################################################################

[include mainsail.cfg]

[save_variables]
filename: ~/printer_data/config/variables.cfg

[respond]
default_type: echo

[force_move]
enable_force_move: True

[gcode_arcs]
resolution: 0.1

[virtual_sdcard]
path: ~/printer_data/gcodes
on_error_gcode: CANCEL_PRINT

######################################################################
# - BASIC STARTER CONFIG ENDER3CNC USING THE 1.1.4 Creality BOARD! -
# https://github.com/RudolphRiedel/CR-10_wiring/blob/master/Ender3_schematic.PDF
######################################################################

[mcu]
# Change serial to your spesific one. SSH into the rasp pi with klipper on and type "ls /dev/serial/by-id/"
#serial: /dev/serial/by-id/usb-1a86_USB_Serial-if00-port0
#serial: /dev/serial/by-id/usb-1a86_USB2.0-Serial-if00-port0           # v1.1.4
serial: /dev/serial/by-id/usb-FTDI_FT232R_USB_UART_A107QHWV-if00-port0 # v1.1.3
restart_method: command

[printer]
kinematics: cartesian
max_velocity: 100
max_accel: 3000
max_z_velocity: 18
max_z_accel: 200

# max_z_velocity: 25
# max_z_accel: 15

[stepper_y]
step_pin: PC6
dir_pin: !PC7
enable_pin: !PD6
microsteps: 16
rotation_distance: 40
endstop_pin: ^PC3
position_endstop: 0
position_max: 266
homing_speed: 100
homing_positive_dir: false

[stepper_y1]
# X driver
step_pin: PD7
dir_pin: PC5
enable_pin: !PD6
microsteps: 16
rotation_distance: 40
endstop_pin: ^PC2

[stepper_z]
step_pin: PB3
dir_pin: PB2
enable_pin: !PA5
microsteps: 16
rotation_distance: 2
endstop_pin: ^PC4
position_endstop: 0
position_max: 80
# position_min: 0
homing_speed: 15
#homing_positive_dir: false

[stepper_x]
# extruder
step_pin: PB1
dir_pin: !PB0
enable_pin: !PD6
microsteps: 16
rotation_distance: 40
endstop_pin: ^PA7          # Nozzle Temp
position_endstop: 0
position_max: 159
position_min: 0
homing_speed: 100
#homing_positive_dir: true

[output_pin ssr]
pin: PD5
pwm: false

# [homing_override]
# gcode:
#     G28 Z        ; Home Z-axis first
#     G28 X        ; Home X-axis
#     G1 X70 F4000 ; Move X to 70mm
#     G28 Y        ; Home Y-axis

[fan]
pin: PB4

######################################################################
# Raspberry Pi
######################################################################

[temperature_sensor RaspberryPi]
sensor_type: temperature_host
min_temp: 10
max_temp: 100

######################################################################
# ST7920 Display
######################################################################
[display]
lcd_type: st7920

cs_pin: EXP1_3                    # CS = Pin 8 PA3
sclk_pin: EXP1_6                  # Clock = Pin 6 PA1
sid_pin: EXP1_4                   # SID / Data = Pin 4 PC1
encoder_pins: ^EXP1_5, ^EXP1_7    # Encoder rotation A/B PD2, PD3
click_pin: ^!EXP1_10              # Push the dial PD2

[output_pin beeper]
pin: EXP1_9
pwm: True
value: 0
shutdown_value: 0


######################################################################
# ST7920 - Plug pin locations
######################################################################

[board_pins]
aliases:
    # EXP1 header
    EXP1_1=<GND>, EXP1_2=<5V>,
    EXP1_3=PA3,   EXP1_4=PC1,
    EXP1_5=PD2,   EXP1_6=PA1,    # Slot in the socket on this side
    EXP1_7=PD3,   EXP1_8=<RST>,
    EXP1_9=PA4,   EXP1_10=PC0
#
#          EXP1:              1 - GND             2 - 5V
#   +-----------------+       3 - LCD_CS          4 - LCD_MOSI  PC1
#   |  2  4  6  8  10 |       5 - BTN A    PD2    6 - LCD_SCK   PA1
#   |  1  3  5  7  9  |       7 - BTN B    PD3    8 - RESET     
#   +------     ------+       9 - Beep     PA4   10 - BTN_ENC   PC0  
#
# Some boards may have the cutout in the wrong location. If so, it may
# be possible to carefully pry the plastic header off of the pins with
# a small screwdriver, then correct the orientation and reapply the
# plastic header.

######################################################################
# Macros
######################################################################

[include E3CNC_ZERO_MACROS.cfg]
[include macros.cfg]

[pause_resume]




#*# <---------------------- SAVE_CONFIG ---------------------->

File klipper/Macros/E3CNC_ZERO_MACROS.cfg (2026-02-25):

# E3CNC macros for workspace XYZ0 positioning

# What the macros do and why: 
#---------------------------------------------
# These macros are to manually set the workspace XYZ0 for any basic milling.
# When you use a "ZERO" macro, it saves your machines "original" position into a variables file. 
# This was done in case of MCU failure, E-stop needs to be pressed or any other reason for the machine to need a firmware reset.
# This removes the need to take notes of the XYZ position before hitting ZERO macros. 


# ! FAILED MID JOB AND FIRMWARE IS RESTARTED !
# NOTE! The following scenario will only work as long as you dont swap out the workpiece for a new one, wanting to try and save the failed job.  
# Scenario: You are in the middle of the job and the MCU crashes, causing a firmware restart. After a firmware restart, you can simply press the "LOAD_OFFSETS" macro
# and the machine will re-home, and go to its last originally saved machine position. From here you can simply press the "ZERO_ALL" macro and the machine sets the workspace XYZ0 to where it was before. 
# You can now restart the original job and might just save your workpiece from being scraps. 

# My manual workpiece ZERO position setup:
# !MAKE SURE THE DREMEL/SPINDLE IS NOT SPINNING!
#-------------------------------------------------
# 1. Attach the workpiece
# 2. Home the CNC
# 3. Move the CNC via mainsail until the bit is ~ at the center of the workpiece.
# 4. Move Z down until ~1mm above the workpiece. 
# 5. Take a thin piece of paper under the bit, move it back and forth while lowering Z, when the bit bites 
# the paper(slight friction), click ZERO_Z macro. Z is now at workpiece Z0.
# 6. Move Z up ~2-3mm or more to avoid crashing if the workpiece is not flat. 
# 7. Move the CNC from mainsail using XY movement to be above the corner you set as origin point in Fusion/CAM.
# 8. Click the ZERO_X and ZERO_Y macro. X and Y is now at workpiece XY0. (dont do Z macro as you already did that)
# 9. Start the job as normal from mainsail. Dont crash, use PPE and be safe.   

[gcode_macro ZERO_X] # Sets workspace X0 position.
gcode: 
  SAVE_VARIABLE VARIABLE=x_offset VALUE={printer.gcode_move.position.x}
  RESPOND PREFIX="info" MSG="Saved X Offset - X={printer.gcode_move.position.x}"
  SET_KINEMATIC_POSITION X=0

[gcode_macro ZERO_Y] # Sets workspace Y0 position.
gcode: 
  SAVE_VARIABLE VARIABLE=y_offset VALUE={printer.gcode_move.position.y}
  RESPOND PREFIX="info" MSG="Saved Y Offset - Y={printer.gcode_move.position.y}"
  SET_KINEMATIC_POSITION Y=0

[gcode_macro ZERO_Z] # Sets workspace Z0 position.
gcode: 
  SAVE_VARIABLE VARIABLE=z_offset VALUE={printer.gcode_move.position.z}
  RESPOND PREFIX="info" MSG="Saved Z Offset - Z={printer.gcode_move.position.z}"
  SET_KINEMATIC_POSITION Z=0

[gcode_macro ZERO_ALL] # Sets workspace XYZ0 position. 
gcode:
  SAVE_VARIABLE VARIABLE=z_offset VALUE={printer.gcode_move.position.z}
  RESPOND PREFIX="info" MSG="Saved Z Offset - Z={printer.gcode_move.position.z}"
  SET_KINEMATIC_POSITION Z=0
  SAVE_VARIABLE VARIABLE=y_offset VALUE={printer.gcode_move.position.y}
  RESPOND PREFIX="info" MSG="Saved Y Offset - Y={printer.gcode_move.position.y}"
  SET_KINEMATIC_POSITION Y=0
  SAVE_VARIABLE VARIABLE=x_offset VALUE={printer.gcode_move.position.x}
  RESPOND PREFIX="info" MSG="Saved X Offset - X={printer.gcode_move.position.x}"
  SET_KINEMATIC_POSITION X=0


[gcode_macro LOAD_OFFSETS] # Homes the machine and goes back to the last coords where XYZ0 was set. 
gcode:
  G28
  {% set svv = printer.save_variables.variables %}
  G1 F3000 X{svv.x_offset} Y{svv.y_offset} Z{svv.z_offset}
 
  RESPOND PREFIX="warn" MSG="Loaded offsets, going to: X={svv.x_offset} Y={svv.y_offset} Z={svv.z_offset}"


[gcode_macro CHECK_OFFSET_XYZ] # Checks what coords are saved and prints them in console. (no movement)
gcode:
  {% set svv = printer.save_variables.variables %}
  RESPOND PREFIX="info" MSG="Current Saved Offset - X={svv.x_offset} Y={svv.y_offset} Z={svv.z_offset}"

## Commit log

2025-11-02 CAD files
2025-11-18 new CAD upload
2025-11-29 Add M3x8 SHSC screws to BOM
2025-12-25 Create DEV] EnderCNC CAD
2025-12-25 Rename to folders
    [Beefy_Dremel_Clamp_REMIX_FACEPLATE.f3d, Ender3_NON_PRO_X_gantry.f3d, Faceplate_step_multicolor.step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]
2025-12-25 Update README to specify KLIPPER in macros
2026-02-18 Add E3CNC Motherboard Documentation to README
    Added documentation for E3CNC motherboard configuration and differences from standard 3D printer setups.
2026-02-24 Add tools documentation for project assembly
2026-02-24 Update title to 'Hardware Bill of Materials (BOM)'
2026-02-24 Add documentation for 3D printed parts
2026-02-24 Add frame assembly documentation
    Document the assembly process for the Ender 3 PRO CNC frame, including parts required, safety notes, and assembly steps.
2026-02-24 Add XZ Carriage Plate Assembly documentation
    This document provides detailed instructions for assembling the XZ carriage plate, including parts required, safety notes, and step-by-step assembly instructions.
2026-02-24 Add Z Carriage Assembly documentation
    Added detailed instructions for Z carriage assembly, including parts required, installation steps, and tips.
2026-02-24 Add documentation for GT2 belts and installation
    This chapter provides instructions on routing GT2 belts, including parts required and installation steps.
2026-02-24 Add Dremel Clamp installation guide
    Added installation instructions for Dremel clamp including parts required and tips.
2026-02-24 Add wiring and electronics setup documentation
    This document provides detailed instructions on wiring and electronics setup, including parts required, limit switch installation, wire management, and electronics enclosure guidelines.
2026-02-24 Add firmware setup documentation for Ender 3 PRO CNC
    This document provides detailed instructions on firmware options and setup for the Ender 3 PRO CNC conversion, including Klipper and GRBL.
2026-02-24 Update MkDocs Material plugin version in deploy.yml
2026-02-24 Split Belts and Spindle into separate files
2026-02-24 Downgrade MkDocs and Material theme versions
2026-02-25 updating doc
    [E3CNC_ZERO_MACROS.cfg]
2026-02-25 Update button formatting in index.md
2026-02-25 Enhance tools and equipment documentation
    Expanded the tools and equipment section with detailed descriptions and recommendations for each tool. Added tips for improved assembly and installation processes.
2026-02-25 Clarify tool names and add tip for extrusion ends
    Updated tool names for clarity and added a tip for squaring ends.
2026-02-25 Update documentation to specify Bill of Materials
2026-02-25 Update and rename xy_joints.md to gantry.md
2026-02-25 Update and rename xz_plate.md to carriage_heatsets.md
2026-02-25 updated readme and moved all development files to a new folder
    [Beefy_Dremel_Clamp_REMIX_FACEPLATE.f3d, Ender3_NON_PRO_X_gantry.f3d, Faceplate_step_multicolor.step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]

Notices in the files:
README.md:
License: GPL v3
